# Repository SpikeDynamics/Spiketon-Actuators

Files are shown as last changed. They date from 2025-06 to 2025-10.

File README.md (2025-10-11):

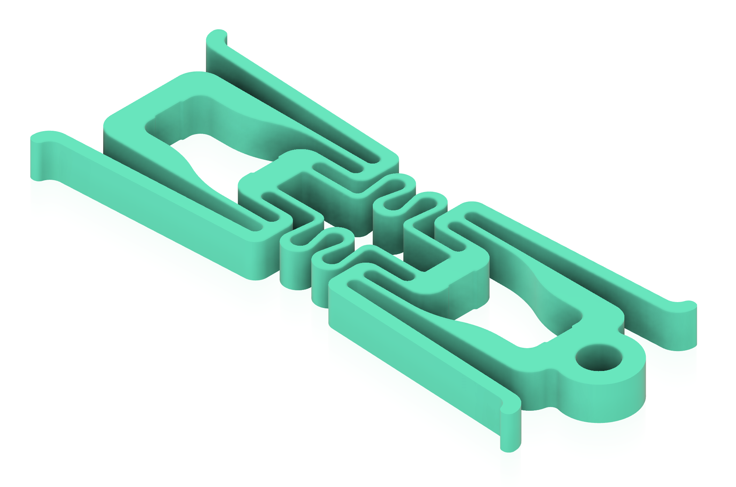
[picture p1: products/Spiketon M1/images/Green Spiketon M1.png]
Spiketon M1 Actuator

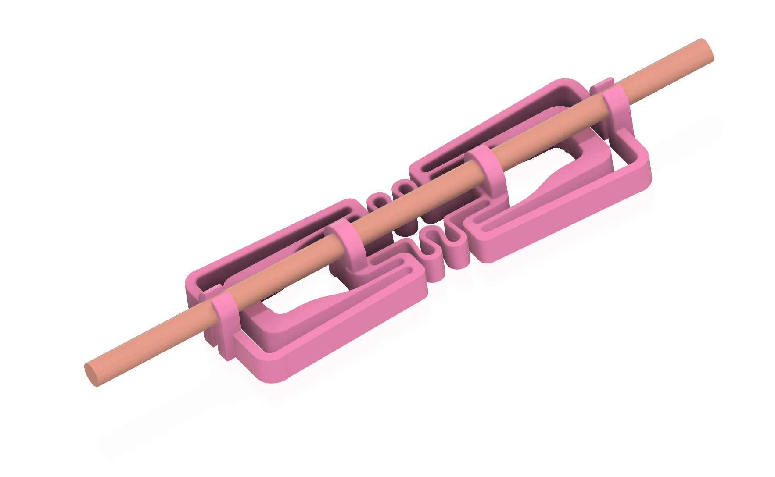
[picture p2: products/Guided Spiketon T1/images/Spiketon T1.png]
Spiketon T1 Actuator


# SpikeTon Actuators Open-Source Piezo Linear Motion (CERN OHL-P v2)




> Ultra-compact, high-force **piezo** actuators for robotics, precision automation, and embedded systems.  
> Hardware, electronics, firmware, CAD, and docs are **fully open** under **CERN OHL-P v2**.

---

<!-- ## 🎬 Project video & what this does -->

<!-- ToDo - ▶️ **Watch:** [SpikeTon overview video](examples/)  -->

- **What this project does**
  - Provides **tiny, high-force linear actuators** driven by piezo stacks.
  - Enables **clean, precise motion** without magnets, gearboxes, oil, or belts.
  - Operates in **tight spaces** and harsh environments (vacuum, radiation, non-magnetic).
  - Includes **CAD, electronics, firmware, and assembly docs** so anyone can build, adapt, and commercialize.

---

## 🔎 At a glance

| Property | Spec / Notes |
|--- |--- |
| Typical drive | 100–150 V piezo drive (sine wave) |
| Nominal force | single stack ~300 N |
| Step | 10 micron - 1mm |
| Frequency range | Up to 20000HZ |
| Key features | Non-magnetic, radiation-tolerant, vacuum-compatible, low profile |
| Materials | Steel / titanium alloys / ceramics (variant-dependent) |
| License | CERN OHL-P v2 (permissive open hardware) |

---

## 🧭 Repo layout

/cad → 3D models (.STEP, .STL, etc.)

/patents  → list of patents

/products  → list of products with /cad, /docs, /examples subfolders

/electronics → Schematics, PCB layouts

/firmware → Control libraries, drivers

/docs → Assembly instructions, performance data

/examples → Sample integrations, demos

LICENSE → CERN OHL-P v2 license text

README.md → This overview

CONTRIBUTING.md → Guidelines for contributors

---

## 🧪 Quick start (10 minutes)

1. **Power & driver**  
   Bench PSU up to **0–150 V** + piezo driver (see `/electronics/`).

2. **Wire it**  
   Follow the wiring diagram in the product’s folder (`/products/<variant>/`).

3. **Signal**  
   Start with a low-amplitude sine at a few hundred Hz, then sweep to find a stable operating region.

4. **Observe motion**  
   Expect sub-mm stepping or amplified stroke (variant dependent).

> ⚠️ **High-voltage safety**: Piezo drivers can be lethal. Use insulated connectors, one-hand rule, ESD protection, and follow creepage/clearance best practices.

---

## 🧭 Products (jump straight in)

- **Guided Spiketon T1 — Guided rod/wire design with outstanding jaws** → [`/products/Guided Spiketon T1/`](products/Guided%20Spiketon%20T1/)  
- **Guided Spiketon T2 — Guided rod/wire design flat** → [`/products/Guided Spiketon T2/`](products/Guided%20Spiketon%20T2/) 
- **Spike AA1 — Amplified actuator** → [`/products/Spike AA1/`](products/Spike%20AA1/)
- **Spike AA2 — Amplified actuator** → [`/products/Spike AA2/`](products/Spike%20AA2/)
- **Spike Rotary Motor R1 — Rotary piezo concept** → [`/products/Spike Rotary Motor R1/`](products/Spike%20Rotary%20Motor%20R1/)  
- **Spiketon M1 — Minimal-BOM linear, simple and strong, double rail** → [`/products/Spiketon M1/`](products/Spiketon%20M1/)
- **Spiketon M2 — Linear, with outstanding jaws, single rail** → [`/products/Spiketon M2/`](products/Spiketon%20M2/)
- **Spiketon M3 — Minimal-BOM linear, double wire rider, regulated stiffness** → [`/products/Spiketon M3/`](products/Spiketon%20M3/)  
- **Spiketon Muscle SM1 — Wire rider** → [`/products/Spiketon Muscle SM1/`](products/Spiketon%20Muscle%20SM1/)

---

## 🔌 Applications

- Precision motion (XY stages, dispensers, 3D printers, laser or camera positioning)  
- Embedded automation where **motors don’t fit** (flat, non-magnetic, clean)  
- Medical / lab tools (high force, small size, low EMI, compact, no lubrication)
- Robotics (low weight, long stroke, compact, silent, keep position without consuming energy)
- Space (low mass, significant force, wide temperature range: from -150C to 320C, vacuum tolerant, radiation hardened) 

---

## 🤝 Contributing

We welcome contributions (hardware, firmware, docs). Please:

1. Read **CONTRIBUTING.md**  
2. Open a **Discussion** for larger proposals  
3. File **Issues** with clear steps / photos / scope  
4. Submit a **PR** with description, images, and validation notes

---

## 💝 Donate / Sponsor

If this project helps your work, consider supporting ongoing development:

- GitHub Sponsors:
- OpenCollective: 
- One-time:

Your support funds test hardware, documentation, and community help.

---

## 🧾 Licensing

This project is licensed under **CERN OHL-P v2** (Permissive).

- SPDX: `CERN-OHL-P-2.0`  
- See `LICENSE` for full terms and attribution requirements.  
- You may use, modify, and commercialize derivatives credit appreciated.

---

## 🙋 Support & questions

- Have questions or want to contribute ideas? Visit our [GitHub Discussions](https://github.com/SpikeDynamics/Spiketon-Actuators/discussions) and share your thoughts!  
- Open an **Issue** for bugs or missing artifacts  
- For collaboration or sponsorship: open a Discussion titled **“Partnering”**

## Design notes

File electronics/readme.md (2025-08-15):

We haven't developed our full-feathered electronics yet. Instead, we used 3rd-party drivers and generators to test the electromechanical capabilities of the Spiketons (multistep), rotational (R1), and amplified actuators (AA1, AA2).

Here we will describe our experience with these 3rd-party electronics. Please don't think this is an advertisement.

We will also publish the Spike Dynamics boards here for conducting experiments and testing. Stay tuned.

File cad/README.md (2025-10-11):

**This folder is reserved for future use.**

The corresponding CAD files for each product are located in the /products/productname/ subfolders.

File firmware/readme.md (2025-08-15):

This folder is for storing firmware files for controllers, drivers, and testing equipment, if any.

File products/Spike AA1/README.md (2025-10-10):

# Amplified Linear Actuator Spike AA1

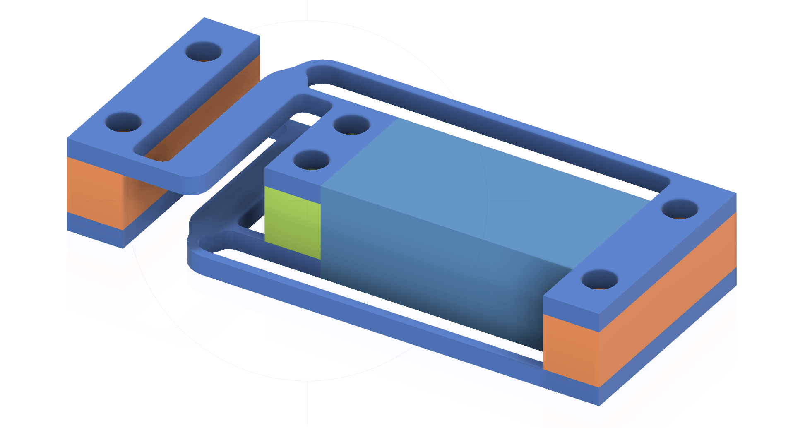
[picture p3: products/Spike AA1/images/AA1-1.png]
Amplified Actuator Spike AA1

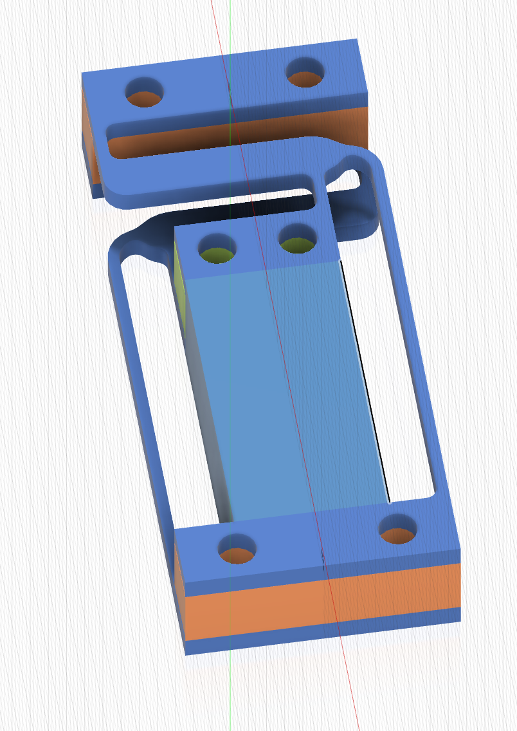
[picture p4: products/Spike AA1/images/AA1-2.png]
Amplified Actuator Spike AA1

AA1 is a lightweight Amplified Actuator for moving the tip of the actuator up to 0.5mm-1mm with a pushing force up to 1000N and high frequency. It can be used as a standalone product or as part of a more complex product (such as Spiketon).

## What AA1 Is For

The purpose of the AA1 is to amplify the oscillations of a piezo stack within a compact volume.
 If the amplification ratio is 10, then with piezo stack vibrations of 100 microns, the AA1 produces oscillations in the same direction of about 1 mm.
 Since levers are involved, the generated force decreases proportionally. However, the compactness of this device is unprecedented.
There are amplified actuators worldwide designed for the same purpose, but they are typically bulky and heavy.

## AA1 Structure

The AA1 consists of several parts.
 Two identical metal plates are placed at the top and bottom. They include all the required links and levers for proper operation.
 Each plate has three pairs of holes on its support pads — used for joining with pins, bolts, or rivets. 
 Although the plates are identical, they are positioned so that the long linkages are on opposite sides.
Between the support pads, thick metal shims are placed. These can be spot-welded, in which case the pairs of holes are not needed.
 A piezo stack is mounted between the middle and the far support pads.
 The whole structure has a bit of spring compliance, so the piezo stack is securely held by elastic force.

## How It Works

Typically, a piezo stack can increase its length by about 0.1%.
 You may find the movements on the video video A1 deformation. The acting forces are shown with arrows.
 When the piezo stack changes its height slightly, the overall height of the device changes by roughly an order of magnitude more (≈1%).
In the accompanying FEA (Finite Element Analysis) simulation, the deformations appear exaggerated — this is a standard visualization mode in SolidWorks, which was used for modeling.
 The same analysis can be performed using other CAD tools such as Autodesk Fusion 360 or Ansys.

## Why Compact Amplified Actuators Matter

Why is it so important to make a compact amplified actuator?
 Because it moves the system from the micron range into the millimeter range.
 Micron-scale mechanisms require extremely precise parts and expensive manufacturing equipment.
 By shifting the motion range to millimeters, the product becomes suitable for mass production with simpler processes and lower precision requirements. This may drastically reduce the cost.
Another consequence: this transition moves the actuator out of the high-cost, ultra-precise, ultra-slow market segment and into the affordable, high-speed market.
 This makes it possible to achieve much higher motion speeds while maintaining excellent precision and repeatability.

## AA1 Application in the Modified M1

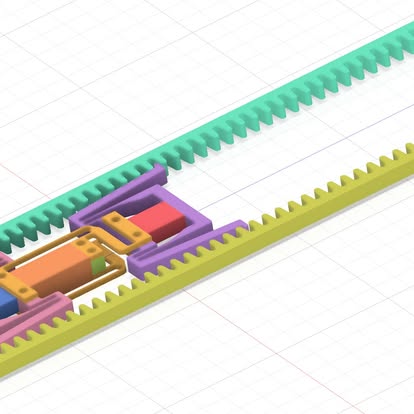
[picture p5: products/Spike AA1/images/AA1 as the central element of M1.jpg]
AA1 as the central element of M1
We used AA1  to create a modified version of the M1 actuator (see figure AA1 as the central element of M1.jpg).
What’s interesting about the result?
 Because each step of the actuator is now 10× longer, we gained the ability to increase the linear motion speed by a factor of 10.
The trade-off is a reduced maximum generated force.
 To compensate, the cross-sectional area of the piezo stack must be increased roughly 10×.
During M1 operation, the ends of its legs follow an elliptical trajectory.
 The ellipse dimensions are determined by the motion of the central section (the body of the actuator) and the front/rear sections (the clamps or jaws).
Previously, the M1 step size was too small to use toothed rails — the distance between teeth was bigger than the step. In other words, the teeth were too small to be properly implemented. 

 Now, with an amplified actuator in the central section, the design allows the use of teeth (see figure).
In this new M1 modification, the carriage legs are held not by friction but by mechanical interlocking with teeth, which provides maximum holding force for configurations using larger piezo stacks and higher forces.
The factor of 10 in this description is just an example — real projects may require higher or lower amplification ratios.

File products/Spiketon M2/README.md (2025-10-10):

Spiketon M2 is a compact, lightweight, high-precision, simple linear actuator with a carriage moving along a single rail.

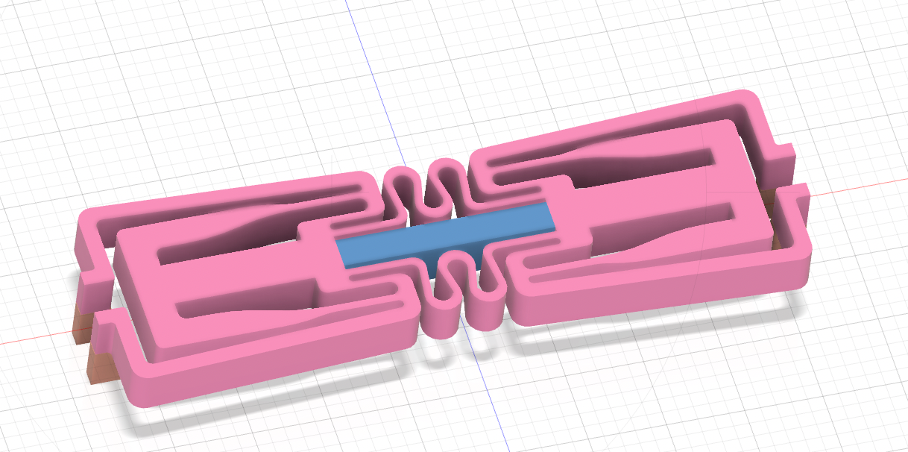
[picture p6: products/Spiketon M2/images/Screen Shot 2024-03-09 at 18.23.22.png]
Spiketon M2

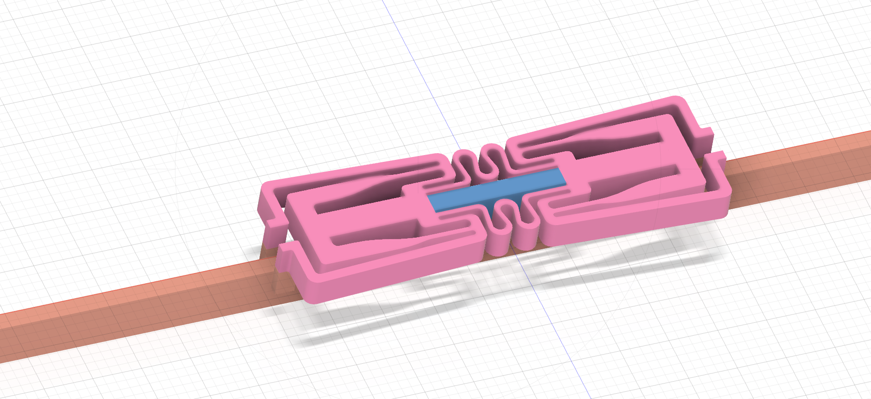
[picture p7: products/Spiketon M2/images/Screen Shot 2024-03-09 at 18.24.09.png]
Spiketon M2 with a rail


Guided Spiketon M2 is a Spiketon Actuator for moving the carriage (the body of the device) back and forth along the rail. 

Front and rear jaws grip the rail at the appropriate time. 

The movement along the rails looks like this:

- grip by rare jaws
- extend the middle part
- grip by the front jaws
- release rare jaws
- contract the actuator's body by side springs
- repeat

Materials:
 - Steel
 - Titanium Alloy Grade 5

   What to choose:
- Steel, when you need the cheapest solution. You need plasticity and hardness at the same time.
- Titanium Alloy Grade 5, when you need a non-magnetic device and some degree of biocompatibility.

  How to cut
  - Wire EDM is the best choice for manufacturing the device
  - CNC is a choice for big actuators. We tried using CNC for small actuators but failed. It is not easy.
  - Laser cutting - not recommended
  - Water jet - it is possible, but not for small actuators.
  - Water jet + Laser cutting - the best approach. It is also the best approach, but the cutting equipment is expensive.
  - 3D-printing - we never tried, but maybe
  - Die cutting (blanking) -  it's a good method to make small, non-expensive actuators (mass production)

  M2 comprises the metal frame having two outstanding jaws.

  The size and force depend on the type of piezostacks used.
   In our experiments, we used piezo stacks of Piezo Instrumente and Thorlabs.

  The output force depends on the cross-sectional area of a piezostack. Even a small piezostack with 2mm*3mm can produce a force of up to 180N. For the project, this means you may use 2mm or 3mm metal sheet for implementation. If you need to implement an actuator with a great force, you have to use actuators with 5mm*5mm, 7mm*7mm or even 15mm*15mm. The last one will provide you with a force of approximately 6000N or even more in a very small size and weight.

  The output force also depends on the friction between the jaws and the rod.

  The difference between M1 and M2. Due to the outstanding jaws, M2 is a little more complicated to implement. It is not enough just to cut the body from a metal plate; it is necessary to implement jaws by welding or other methods. 

    Please ask us about these things if you need more information.

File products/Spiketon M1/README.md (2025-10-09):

Spiketon M1 is a simple, compact, lightweight, high-precision, linear actuator that moves a carriage along rails.

Spiketon M1

Guided Spiketon M1 is a Spiketon Actuator for moving the carriage (the body of the device) back and forth along the rails. 

Front and rear clamps grip the rails at the appropriate time. 

The movement along the rails looks like this:

- grip by rare clamps
- extend the middle part
- grip by front clamps
- release rare clamps
- contract the actuator's body by side springs
- repeat

Materials:
 - Steel
 - Titanium Alloy Grade 5

   What to choose:
- Steel, when you need the cheapest solution. You need plasticity and hardness at the same time.
- Titanium Alloy Grade 5, when you need a non-magnetic device and some degree of biocompatibility.

  How to cut
  - Wire EDM is the best choice of manufacturing the device
  - CNC is a choice for big actuators. We tried to use CNC for small actuators and failed. It is not easy.
  - Laser cutting - not recommended
  - Water jet - it is possible, but not for small actuators.
  - Water jet + Laser cutting - the best approach. It is also the best approach, even for ceramics
  - 3D-printing - we never tried, but maybe
  - Die cutting (blanking) -  it's a good method to make small, non-expensive actuators (mass production)

  M1 comprises the metal frame having two clamps(two pairs of legs)
  You may use one Spiketon M1 or two for 2-levels rails. One M1 is for rough movement and the second M1 is for fine movement.

  The size and force depend on the type of piezostacks used.
   In our experiments, we used piezo stacks of Piezo Instrumente and Thorlabs.

  The output force depends on the cross-sectional area of a piezostack. Even a small piezostack with 2mm*3mm can produce a force of up to 180N. For the project, this means you may use 2mm or 3mm metal sheet for implementation. If you need to implement an actuator with a great force, you have to use actuators with 5mm*5mm, 7mm*7mm or even 15mm*15mm. The last one will provide you with a force of approximately 6000N or even more in a very small size and weight.

  The output force also depends on the friction between the jaws and the rod.

    Please ask us about these things if you need more information.

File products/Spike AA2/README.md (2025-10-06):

Amplified Linear Actuator Spike AA2

AA2 is a lightweight amplified actuator that moves the tip up to 0.5mm-1mm with a pushing force of up to 1000N and operates at high frequency. It can be used as a standalone product or as a part of a more complex product (like Spiketon).

The difference between AA2 and AA1 is in their design purposes. AA1 has been designed to ba as simple as possible. While AA2 is more advanced, it comes with a more complex assembly.

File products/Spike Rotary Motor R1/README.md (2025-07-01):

The Spike Rotary Motor R1 rotates a shaft using a set of linear mechanisms that resemble simplified Spiketons. While R1 offers both advantages and drawbacks, it is better viewed as a thought-provoking concept than as a ready-to-use product.

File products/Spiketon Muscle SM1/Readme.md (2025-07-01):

Spiketon Muscle SM1 is a compact, lightweight, high-precision, simple pulling linear actuator. Like a natural muscle, it pulls on tendons to move bones — or metal parts — with significant force.

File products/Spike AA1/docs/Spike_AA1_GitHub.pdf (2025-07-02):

## Spiketon Amplified Actuator (Spike AA1)

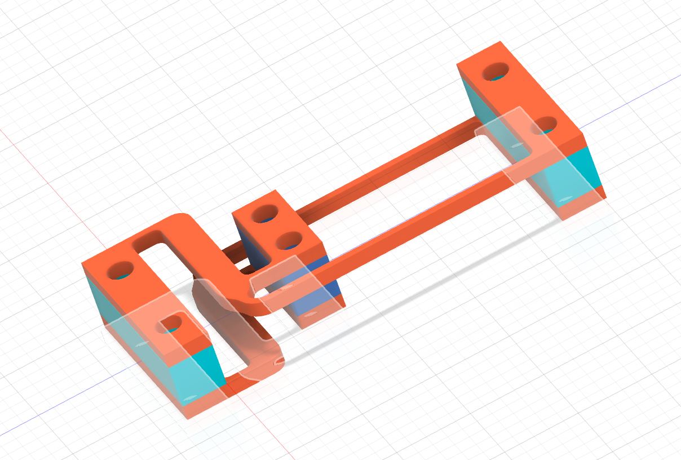
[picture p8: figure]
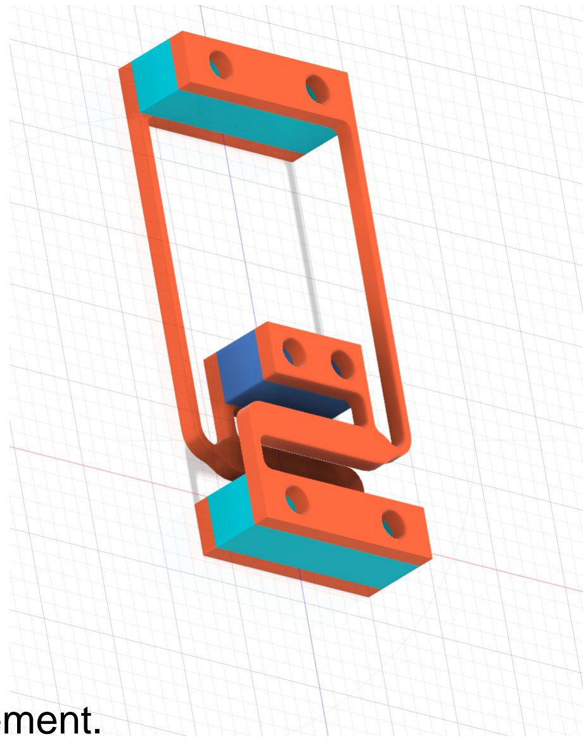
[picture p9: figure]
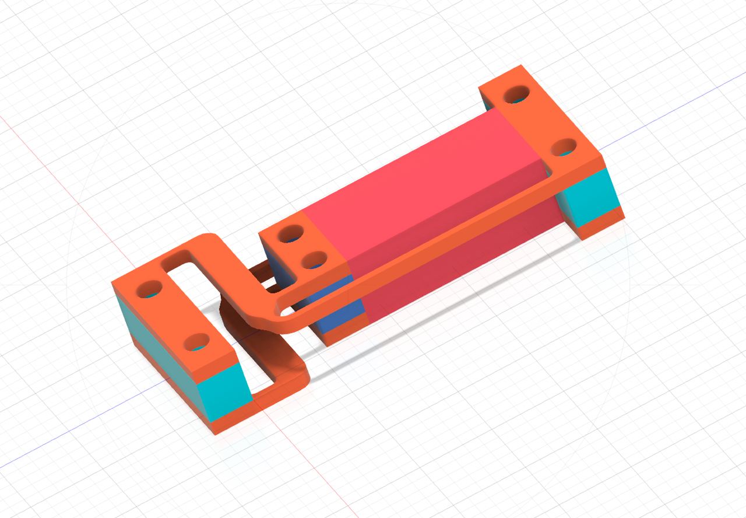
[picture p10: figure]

Figure 0 - Three views of the Spike AA1 frame and piezo stack arrangement.

Spike AA1 is a compact amplified actuator designed to dramatically boost the tiny movements of a

piezoelectric stack into useful, macroscopic displacements. At the heart of this design is a principle

of mechanical amplification that transforms microns into millimeters - and complexity into simplicity.

Structure and Materials

The actuator consists of:

- A frame made from two identical flat metal parts.
- A piezoelectric stack, placed between two inner plates of the frame.

The two flat frame components are joined using bolts or rivets through holes at their ends. Between

these plates are metal shims, which create a controlled spacing - the thickness of the shims

determines the gap between the two frame layers. The piezo stack, though not shown in the video,

sits snugly between the inner plates and expands slightly in height when activated.

Amplification Principle

A typical piezoelectric stack can expand by about 0.1% to 0.2% of its length - an extremely small

change. However, in the Spike AA1 architecture, this tiny vertical movement is mechanically

amplified by a factor of 10× or more, causing the overall actuator to elongate by around 1% of its

height.

The mechanism relies on elastic deformation of the frame. When the piezo stack presses against

the plates, the whole structure flexes, and leveraged movements magnify the displacement.

Simulation and Visuals

The accompanying simulation video was created in SolidWorks, which includes a "dramatized

deformation" mode. This exaggerates structural bending for clarity - a kind of engineering

Hollywood. In reality, the displacements are more subtle, but still significant and functional.

Why Miniaturization Matters

The compact size of AA1 (and its successor, AA2) is not just an engineering curiosity - it's the key to

unlocking a new class of electromechanical systems.

- From microns to millimeters: Micro-scale piezo movements are difficult and expensive to

manufacture due to the need for ultra-precise tooling. But if these micro-motions are amplified

into millimeter-scale displacements, simpler and cheaper production methods become

possible.

- Mass-market access: Most piezo-based systems remain trapped in slow, ultra-precise,

high-cost niches. Spike AA1 opens the door to affordable, fast, and scalable applications -

without sacrificing accuracy or repeatability.

Can Spike AA1 Replace a Standard Piezo Stack?

Yes - Spike AA1 can replace a conventional piezoelectric stack of the same size in many designs.

For example, in the central section of the Spiketon M1 actuator, the piezo stack with spring-loaded

supports can be replaced by Spike AA1 (or its successor, AA2).

Such a replacement makes sense when the speed of motion is more critical than the force applied

by the actuator. A standard piezo stack of the same length typically cannot achieve large step

displacements. As a result, the overall speed of motion becomes severely limited.

By contrast, Spike AA1 uses mechanical amplification to extend the displacement range

significantly. This enables much faster motion - even if the force per step is reduced - making it an

ideal option for systems where agility and response time are more important than brute force.

Design Limitation of AA1: Torsional Distortion

One challenge in the design of Spike AA1 comes from how the internal forces are transmitted

through the structure. When the piezoelectric stack expands, it pushes against the upper and lower

inner plates, causing the overall frame to expand vertically through elastic deformation. However,

due to the diagonal path of force transmission from the flexing plates, a small amount of torsional

twisting can occur in the actuator.

In many applications, this torsion is negligible - the surrounding mechanical assembly constrains the

actuator and prevents visible twisting. But in some precision-sensitive contexts, this torsional

distortion can affect accuracy or alignment.

This limitation is eliminated in the improved version, Spike AA2, which includes geometric and

structural refinements that suppress torsion even under high loads.

The twisting effect is illustrated in the simulation video using exaggerated deformation mode. In

real-world use, the distortion is minimal and would likely go unnoticed without this visualization.

Applications and Outlook

Amplified actuators like Spike AA1 could be integrated into:

- Small walking robots
- Precision pumps and valves
- Lightweight medical devices
- Space-grade micromechanical systems

Its simplicity, compactness, and amplification efficiency make it ideal for environments where space

is tight, energy is limited, and precision is vital.

Video 1 - Amplified Motion

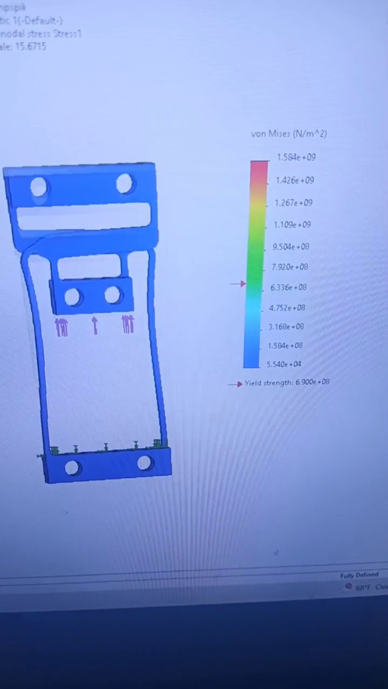
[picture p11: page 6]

Figure 1 - Spike AA1 in action: amplified vertical motion.

video1.mp4 (https://github.com/SpikeDynamics/Spiketon-Actuators/tree/main/products/Spike%20AA1/video/video1.mp4)

Video 2 - Torsional Distortion (Exaggerated)

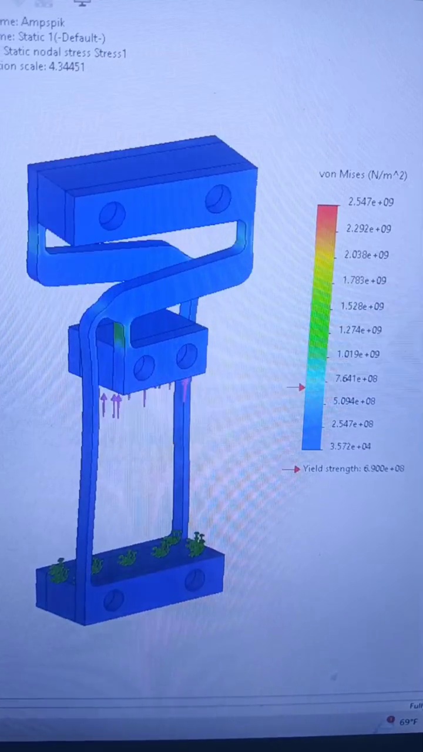
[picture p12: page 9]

Figure 2 - Exaggerated torsional twist in Spike AA1.

video2.mp4 (https://github.com/SpikeDynamics/Spiketon-Actuators/tree/main/products/Spike%20AA1/video/video2.mp4)

Video 3 - Torsional Distortion from End View

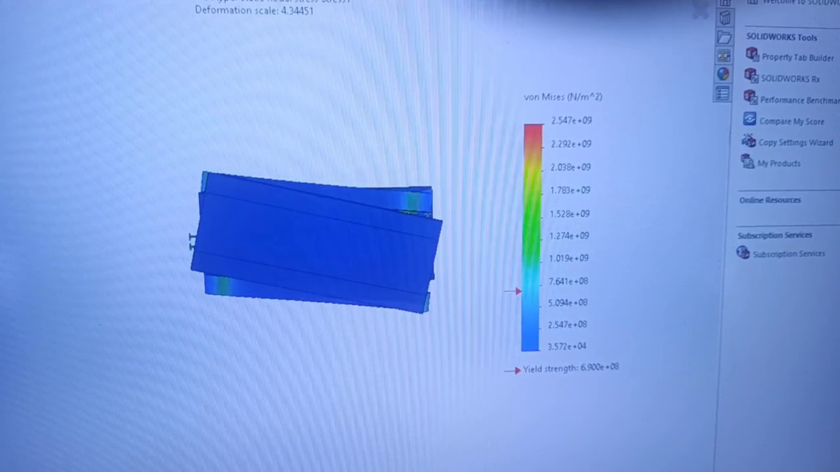
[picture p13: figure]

Figure 3 - End-view of torsional distortion in Spike AA1.

video3.mp4 (https://github.com/SpikeDynamics/Spiketon-Actuators/tree/main/products/Spike%20AA1/video/video3.mp4)

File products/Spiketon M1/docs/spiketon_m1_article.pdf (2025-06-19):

## Spiketon M1: A Compact, High-Precision Guided

## Actuator

Spiketon M1 is a high-performance guided actuator developed by Spike Dynamics. It functions either as a moving carriage that travels along external rails (hence “guided”), or as a stationary unit that moves rails—or loads— relative to itself.

At its core, Spiketon M1 is built from a lightweight structural frame, manufactured from steel, titanium alloy, technical ceramics, or high-strength polymers. In the most basic version, its muscle-like mechanism can even be stamped from sheet metal in a single press motion, offering extremely low-cost fabrication.

How It Works

The actuator is powered by miniature piezoelectric piezo stacks.
The green and orange modules visible in the drawings are these active

components.

These modules expand slightly (about 0.1%–0.2% of their length) when a sinusoidal voltage of 100–150V is applied. Due to the elastic constraints of the surrounding frame (beige color), this causes a controlled extension and contraction of the actuator body.

Green modules cause lateral movement of the “feet” or clamps, pushing outward to grip surfaces.
An orange module controls elongation or shortening of the actuator body.

This cyclical coordination enables inchworm-like locomotion:

The front clamps engage with the surrounding structure. The body elongates via the orange module.
The rear clamps engage, front clamps release.
The orange module contracts—pulling the rear end forward.

•

•

1.
2.
3.

4.

This simple but powerful motion is repeated at high frequencies, enabling rapid bidirectional movement with high reliability.

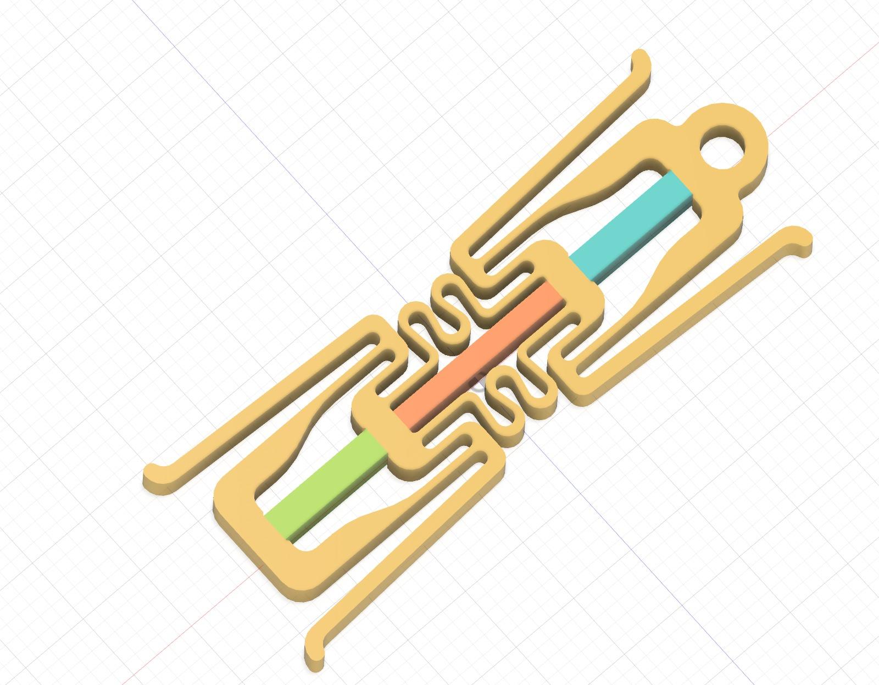
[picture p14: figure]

Drawing 1: Structure of Spiketon M1 showing piezoelectric modules (green, orange, blue) embedded in a flexible frame (beige).

Performance and Materials

Each piezo stack—just 2 mm × 3 mm in cross-section—can generate forces up to 100–300 N, capable of moving 10–30 kg loads. The materials used, such as ceramic and titanium alloys, allow operation in extreme environments with wide temperature swings, radiation exposure, and without any need for lubrication.

Non-magnetic (ideal for sensitive environments)
Compact and scalable
High-precision, with excellent repeatability Fully solid-state, with no rotating parts or gears

Why We Call It a Muscle

A ring-shaped anchor on the actuator’s frame allows it to be connected to a tendon, mimicking biological muscle action. As the actuator contracts and expands, it pulls the tendon with significant force—just like a bicep pulling a forearm.

In fact, a single Spiketon M1 unit measuring 10 mm thick, 15 mm wide, and 40 mm long can replace a human bicep in terms of output force—while operating up to 10× faster, and with significantly less weight and volume.

•
•
•
•

Mounting and Rail Interface

Drawing 2 shows how the Spiketon M1 actuator can be mounted for guided motion along a rail. In this configuration, the actuator body (gold) is enclosed between two rigid blue rail elements, while the red component—screwed into the central threaded ring—acts as a mechanical driver that pushes or pulls against the environment.

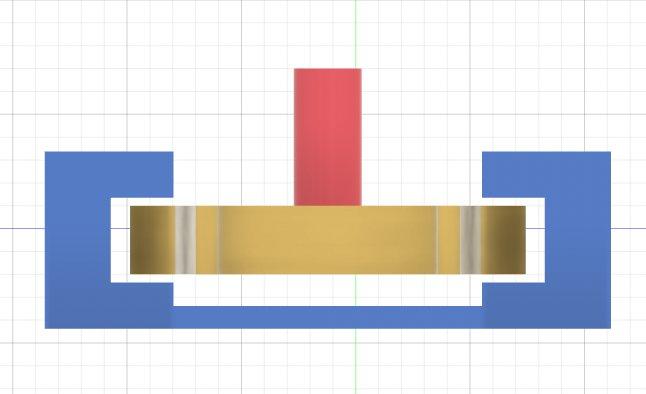
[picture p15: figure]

Drawing 2: Example of Spiketon M1 moving along a rail. The actuator is clamped between two structural rails (blue), and a threaded red screw transmits force from the actuator's internal ring.

Physical Rail Implementation

Drawings 3 and 4 show real-life examples of aluminum profiles that can be used as rails for the Spiketon M1 actuator. These extrusions are readily available online and provide a lightweight, rigid, and manufacturable track for actuator motion.

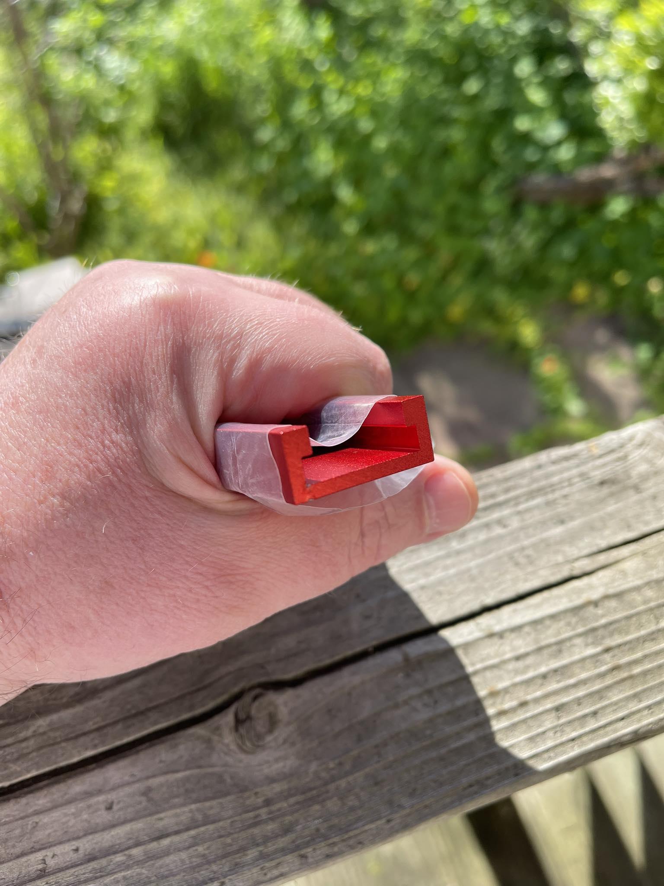
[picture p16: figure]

Drawing 3: Red aluminum rail profile shown in hand. The internal groove accommodates the actuator body, allowing guided movement.

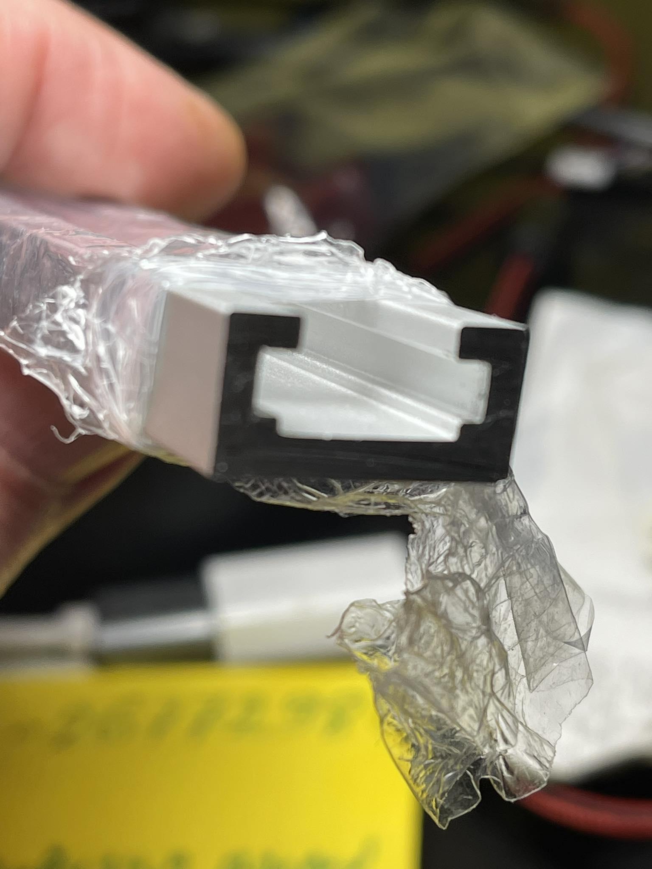
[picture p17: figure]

Drawing 4: Silver anodized aluminum profile with internal channel, suitable for integration with Spiketon M1.

Prototyping and Materials

Drawing 5 shows a partially assembled prototype of the Spiketon M1 actuator. The black frame is made from high-carbon blade steel—originally chosen for its hardness and cutting resistance. However, later experiments showed that this material is suboptimal for actuators: although extremely hard, it lacks the necessary balance of strength and ductility.

The lesson: actuator frames benefit more from “aerospace” steels and alloys than from “sword-grade” ones. Modern stainless alloys with high toughness and moderate hardness performed much better.

In this image, two piezo stacks have been inserted into their slots, while the central slot awaits the third stack. No glue is needed: each module is held in place by the elastic tension of the frame itself. In essence, the entire black frame functions as a single precision spring.

Later tests also demonstrated excellent results with titanium alloys, including Grade 5 and nitinol. These materials produce a gray actuator frame that is both visually refined and functionally superior to black steel—especially in demanding environments.

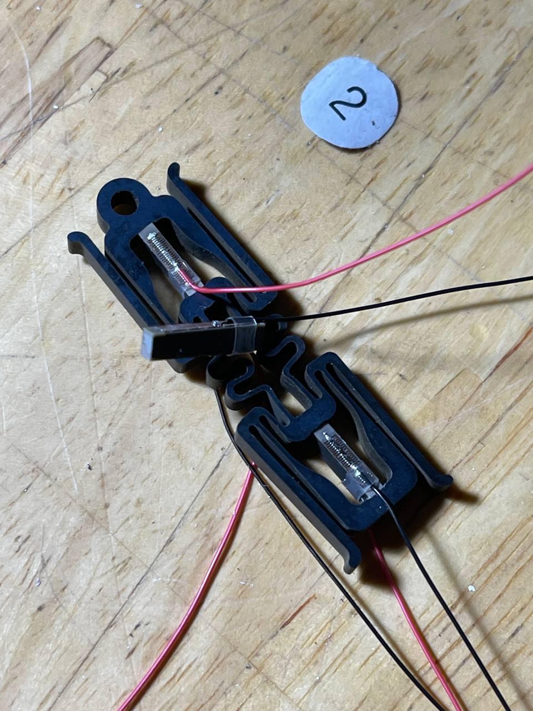
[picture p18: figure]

Drawing 5: Partially assembled Spiketon M1 prototype. Two piezo stacks are installed, and the frame is made of high-carbon blade steel, which was later replaced by aerospace-grade alloys for better performance.

Full Assembly Actuation

This second video shows the fully assembled Spiketon M1 actuator in operation. Here, the actuator is compressed between two rigid surfaces— simulating the inner walls of a guiding rail.

The visible movement of the legs is caused by a single piezoelectric stack inside the actuator. Although the displacement appears minimal, it is sufficient to press the actuator’s legs outward against the rail surfaces. This micro-motion is critical to ensuring secure grip and repeatable locomotion at high frequency.

Your browser does not support the video tag.

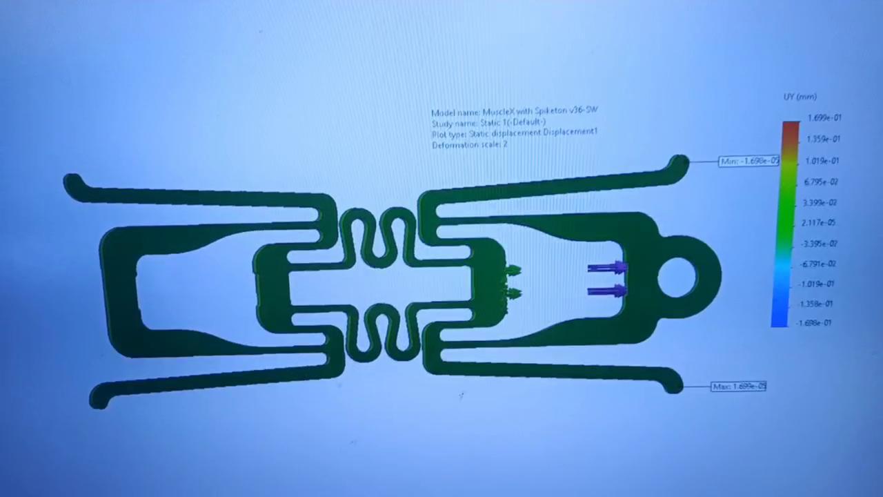
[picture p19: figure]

Drawing 7: Still frame from a video showing the fully assembled Spiketon M1 actuator. A single piezo stack creates a small but effective outward motion of the legs under compression between rail walls.

Design Simplification

Drawing 8 presents a later, more streamlined version of the Spiketon M1 actuator. Compared to the earlier design shown in Drawing 1, this version features fewer decorative spring curves surrounding the central piezo stack.

Instead of using multiple curled or coiled springs, the central body is now suspended by slightly curved elastic plates. These simplified elements serve exactly the same functional purpose—flexibly supporting the central section— while offering a more compact and manufacturable design.

This design evolution was the result of extensive simulation and testing, confirming that elegant simplicity can match the performance of more visually elaborate structures.

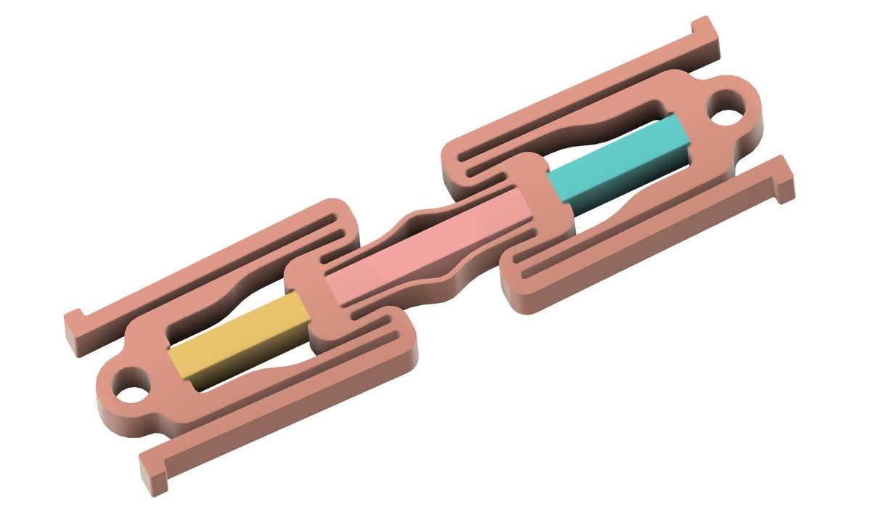
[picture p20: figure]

Drawing 8: Streamlined Spiketon M1 design with curved plates instead of coiled springs. A result of iterative testing and structural optimization.

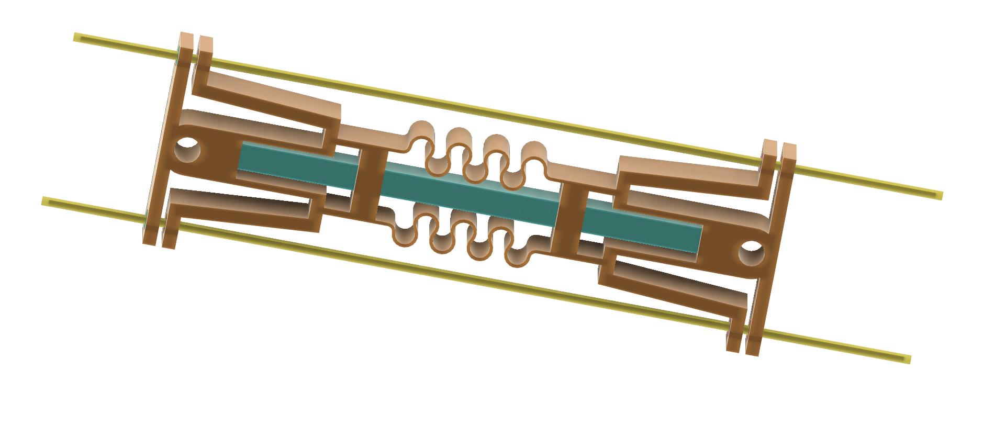
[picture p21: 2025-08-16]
products/Spiketon M3/images/M3.png

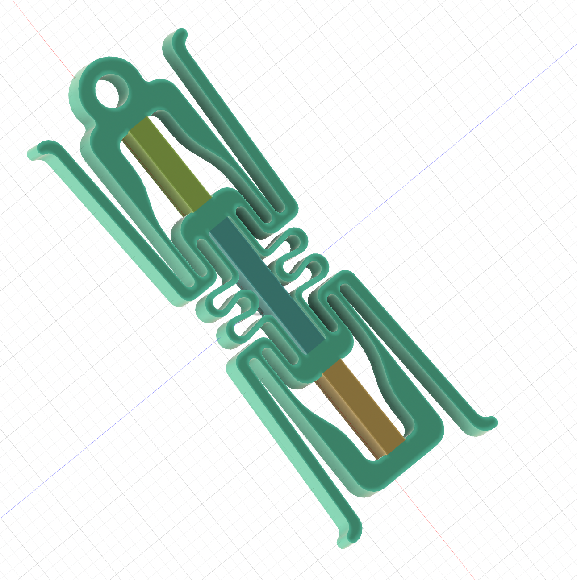
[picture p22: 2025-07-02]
products/Spiketon M1/images/Screen Shot 2024-10-12 at 17.50.14.png

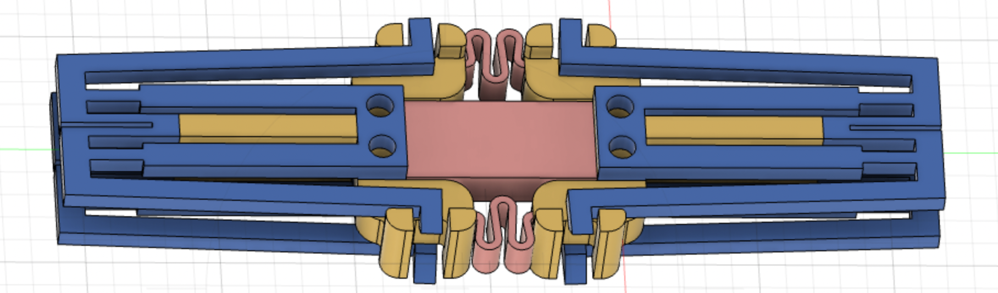
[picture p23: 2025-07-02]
products/Spiketon Muscle SM1/images/Screen Shot 2022-07-18 at 21.57.14.png

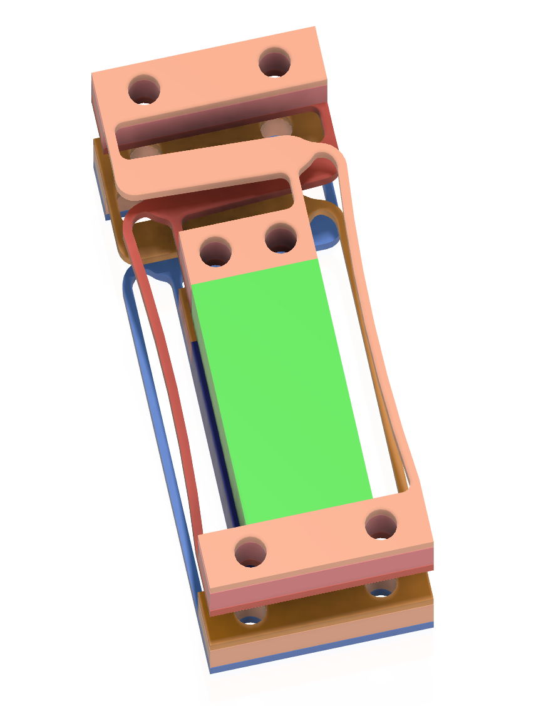
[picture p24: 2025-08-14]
products/Spike AA1/images/AA1-extended and nonextended.png

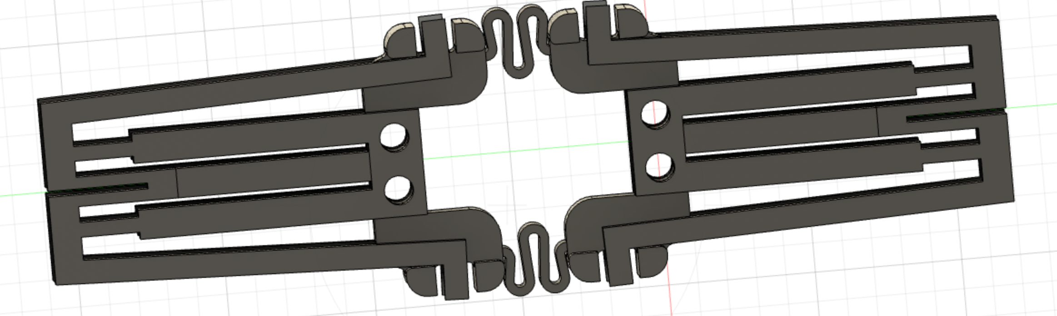
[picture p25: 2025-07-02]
products/Spiketon Muscle SM1/images/Screen Shot 2022-07-16 at 21.08.01.png

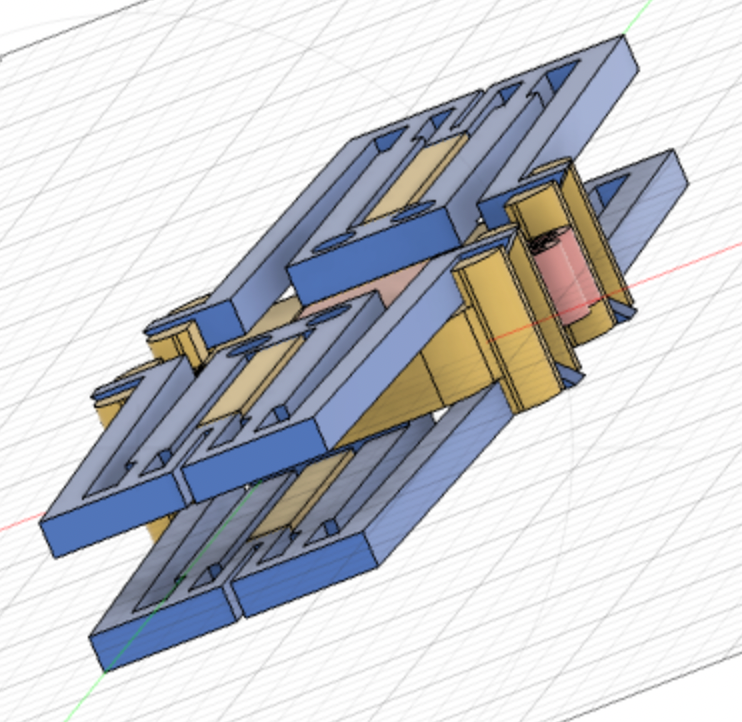
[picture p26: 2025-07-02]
products/Spiketon Muscle SM1/images/Screen Shot 2022-07-18 at 21.58.44.png

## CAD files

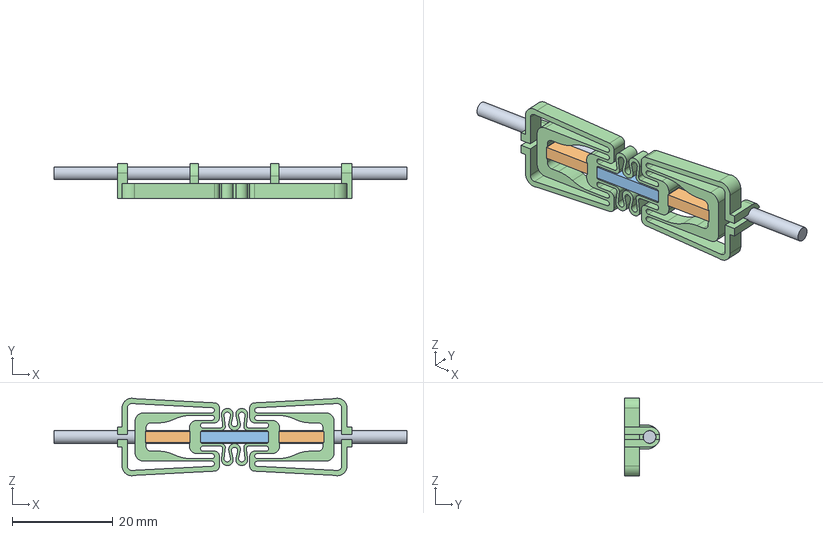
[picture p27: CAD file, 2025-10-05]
products/Guided Spiketon T1/cad/SpiketonT1Final v1.step
70.0 x 7.00 x 15.4 mm
Rod (1)
FrontPiezo
RarePiezo
MiddlePiezo

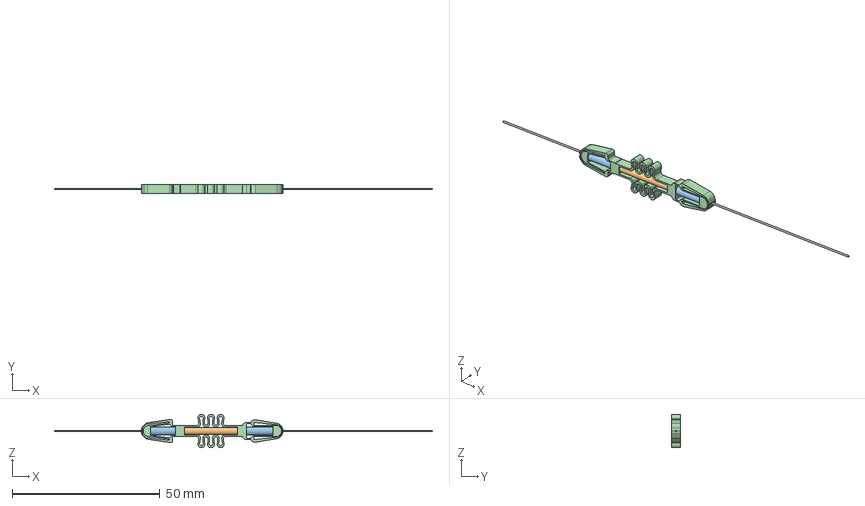
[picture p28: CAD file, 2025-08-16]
products/Guided Spiketon T2/cad/T2 v1.step
128.0 x 3.17 x 11.3 mm
Wire (1) (1)
Middle Piezo
Front Piezo
Rare Piezo
Frame

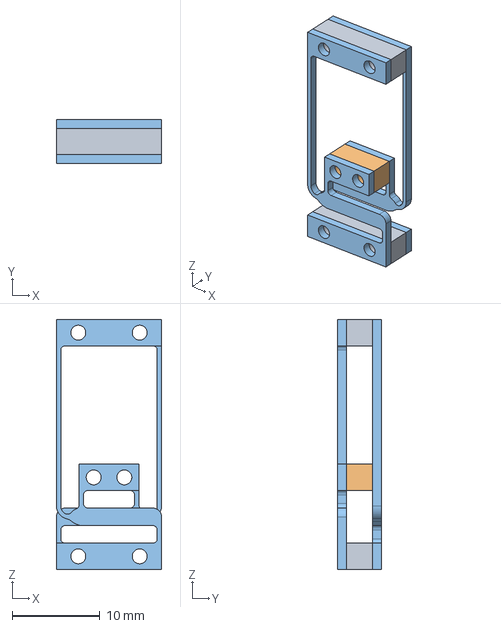
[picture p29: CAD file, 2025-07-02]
products/Spike AA1/cad/Nondeformed AA1 v1.step
12.0 x 5.00 x 28.5 mm

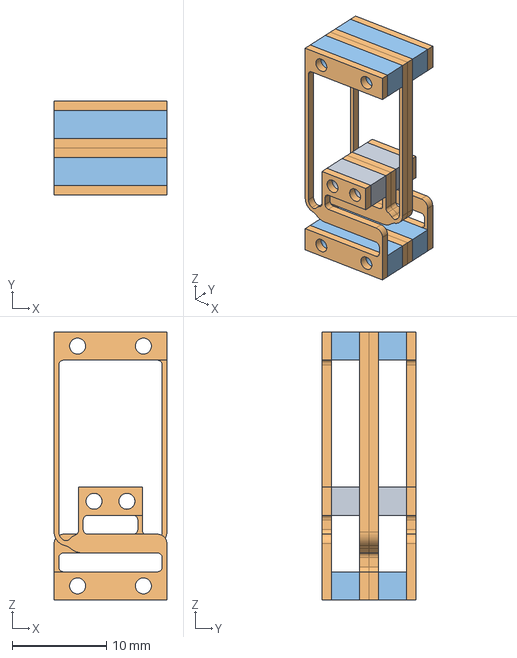
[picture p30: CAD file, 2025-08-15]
products/Spike AA2/cad/AA2 v1.step
12.0 x 10.0 x 28.5 mm

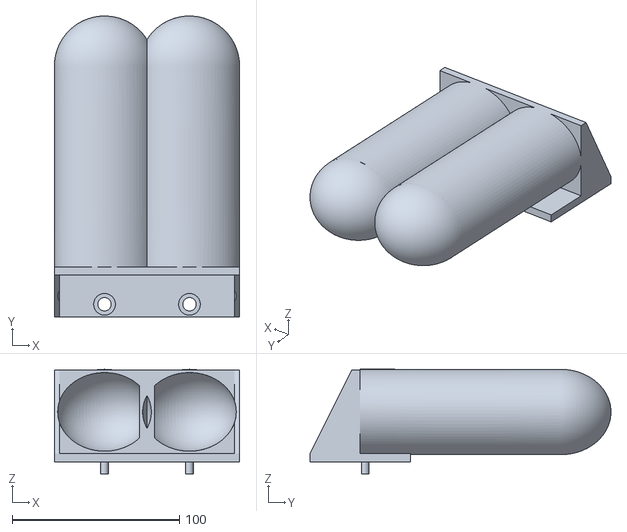
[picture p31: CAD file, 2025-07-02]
products/Spike AA2/docs/doublebot.stl
110.8 x 180.0 x 62.5

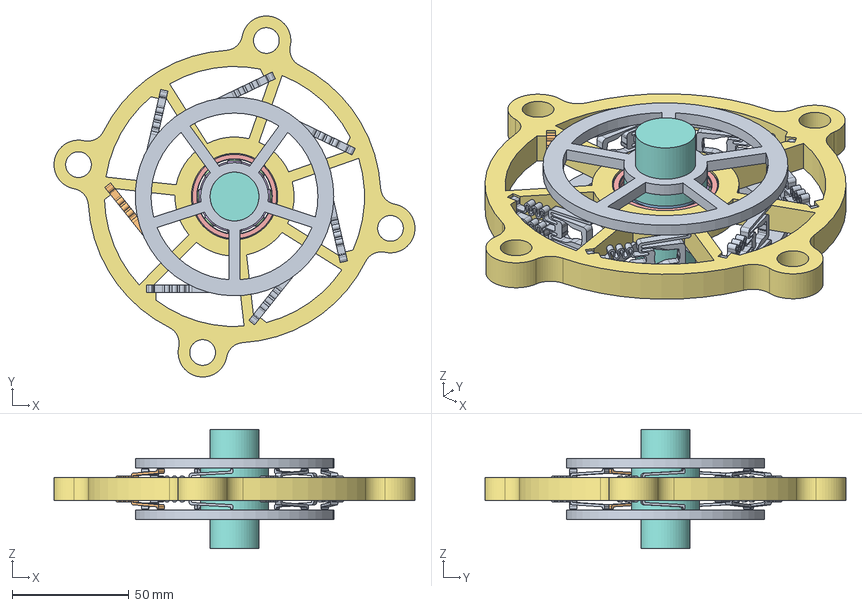
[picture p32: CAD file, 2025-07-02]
products/Spike Rotary Motor R1/Rotary Motor R1 GitHub v1.step
154.6 x 154.6 x 51.0 mm
FlattyFSpring
FlattyFSpring (1)
FlattyFSpring (2)
FlattyFSpring (3)
FlattyFSpring (4)
FlattyFSpring (5)
FlattyFSpring (6)
5972K245_Ball Bearing

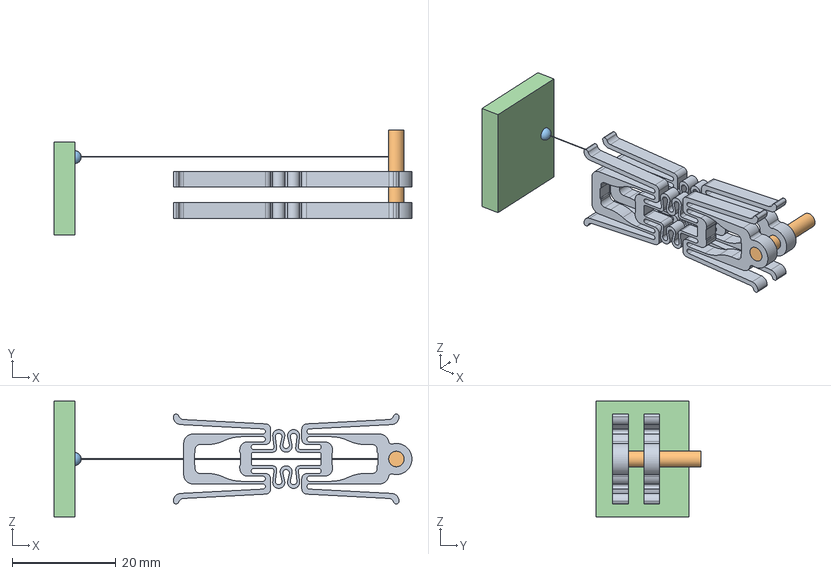
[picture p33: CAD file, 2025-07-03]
products/Spiketon M1/cad/Spiketon M1 Two Levels v1.step
69.0 x 20.2 x 22.3 mm
NicerFlattyF (2) (2)
NicerFlattyF (2)
Cyl
Sharik

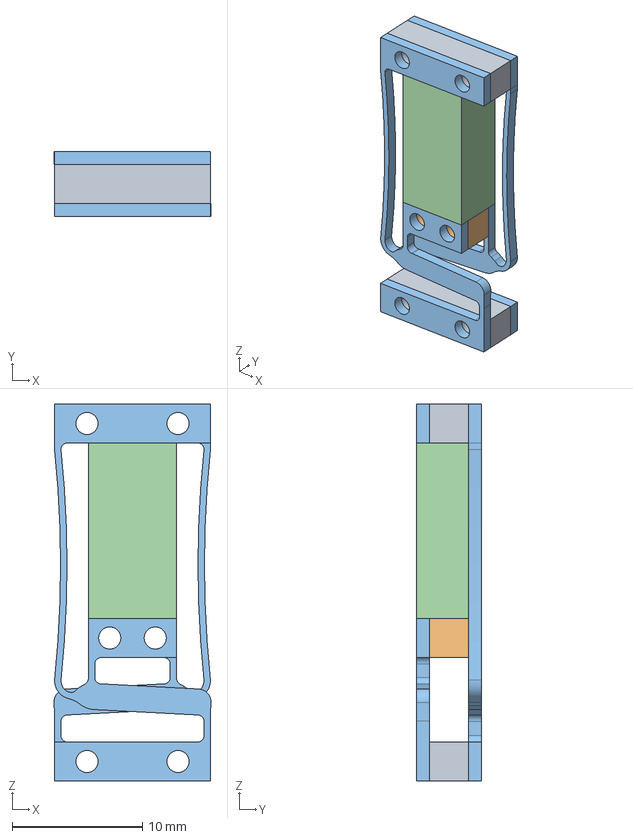
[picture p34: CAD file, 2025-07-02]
products/Spike AA1/cad/Deformed AA1 v1.step
12.1 x 5.00 x 29.0 mm
DefAA1Part (1)
DefSpiketonPart
Piezo (5)

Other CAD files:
products/Guided Spiketon T1/cad/SpiketonT1Final v1.f3d
products/Guided Spiketon T2/cad/T2 v1.f3d
products/Guided Spiketon T2/cad/T2 v1.stl
products/Spike AA2/cad/AA2 v1.f3d
products/Spike AA2/cad/AA2 v1.stl
products/Spike Rotary Motor R1/Rotary Motor R1 GitHub v1.f3d
products/Spike Rotary Motor R1/Rotary Motor R1 GitHub v1.stl
products/Spiketon M1/cad/Spiketon M1 Two Levels v1.f3d

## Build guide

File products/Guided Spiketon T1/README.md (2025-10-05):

Guided Spiketon T1 is a Spiketon Actuator for moving back and forth along a rod or a wire (guide). 

Guided Spiketon T1

Guided Spiketon T1 is a Spiketon Actuator for moving the rod (guide) back and forth along the actuator body. 

Front and rear clamps grip the wire at the appropriate time. 

The movement along a wire or a rod looks like this:

- grip by rare clamps
- extend the middle part
- grip by front clamps
- release rare clamps
- contract the actuator's body by side springs
- repeat

Materials:
 - Steel
 - Titanium Alloy Grade 5
 - Nitinol
 - Ceramics
   
   What to choose:
- Steel, when you need the cheapest solution. Keep in mind that steel is a magnetic material. You need plasticity and hardness at the same time.
- Titanium Alloy Grade 5, when you need a non-magnetic device and some degree of biocompatibility.
- Nitinol, when you need biocompatibility
- Ceramics - never use ceramics.

  How to cut
  - Wire EDM is the best choice for metal
  - CNC is a choice for big actuators. We tried to use CNC for small actuators and failed. It is not easy.
  - Laser cutting - not recommended
  - Water jet - it is possible, but not for small actuators.
  - Water jet + Laser cutting - the best approach. It is also the best approach, even for ceramics
  - 3D-printing - we never tried, but maybe
  - Die cutting (blanking) -  it's a good method to make small, non-expensive actuators (mass production)

  T1 comprises the metal frame, two jaws, and 1 or 2 outstanding elements (holders with a hole)
  Only a 3D printer allows for making the frame as a whole. Other methods demand welding.

  The size and force depend on the type of piezostacks used.
   In our experiments, we used piezo stacks of Piezo Instrumente and Thorlabs.

  The output force depends on the cross-sectional area of a piezostack. Even a small piezostack with 2mm*3mm can produce a force of up to 180N. For the project, this means you may use 2mm or 3mm metal sheet for implementation. If you need to implement an actuator with a great force, you have to use actuators with 5mm*5mm, 7mm*7mm or even 15mm*15mm. The last one will provide you with a force of approximately 6000N or even more in a very small size and weight.

  The output force also depends on the friction between the jaws and the rod.

    Please ask us about these things if you need more information.

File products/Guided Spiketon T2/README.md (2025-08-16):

Guided Spiketon T2
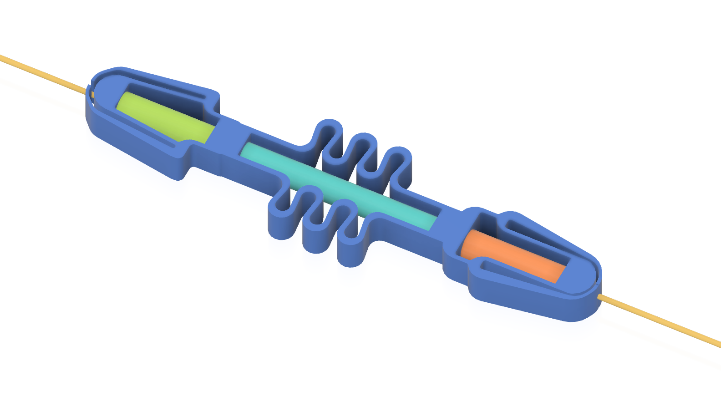
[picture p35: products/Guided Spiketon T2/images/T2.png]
Guided Spiketon T2


Guided Spiketon T2 is a Spiketon Actuator for moving back and forth along a rod or a wire (guide). 

Front and rare clamps grip the wire at the appropriate time. This design has its advantages and disadvantages. 
  Advantages: very simple and easy to implement.
  Disadvantages: Piezo stacks require a central hole (this is a bit more expensive). The jaws here are wearing out quickly. The metal frame is also subject to wear. 

 The central part may contain various implementations. It uses the same approach as M1-M3 and T1
